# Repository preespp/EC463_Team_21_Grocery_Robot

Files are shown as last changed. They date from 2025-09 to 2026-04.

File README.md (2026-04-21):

# [Team 21 GOFR: Grocery Operations & Fulfillment Robot](https://gofr-2026.github.io/)
<p align="center">
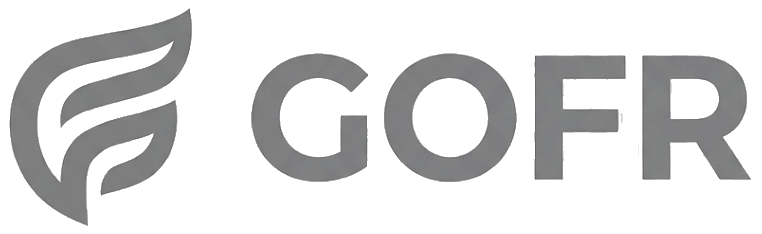
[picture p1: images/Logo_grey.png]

</p>
Our group’s vision is to make everyday shopping more efficient and inclusive. We aim to address issues that would benefit both owners and customers through an intelligent, multi-functional robotic system to improve shelf management and customer experience. Our final delivery would be a multi-wheel robot with functional robotic arm(s), sensors, cameras, and artificial intelligence to assist in employee stocking and customer shopping.

<p align="center">
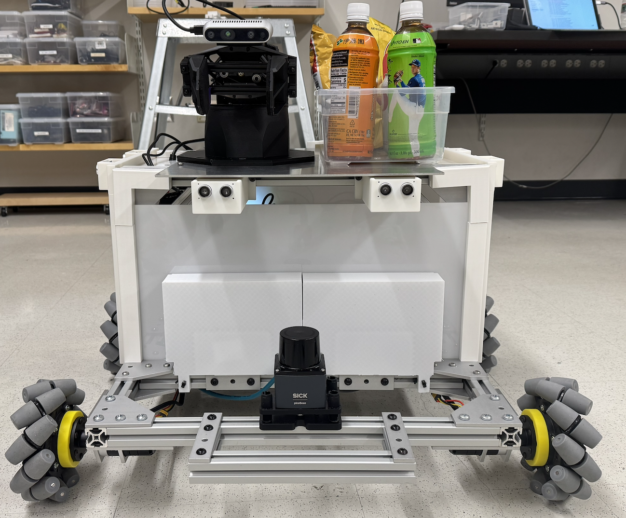
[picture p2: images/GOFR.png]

</p>
<p align="center">
GOFR
</p>

<p align="center">
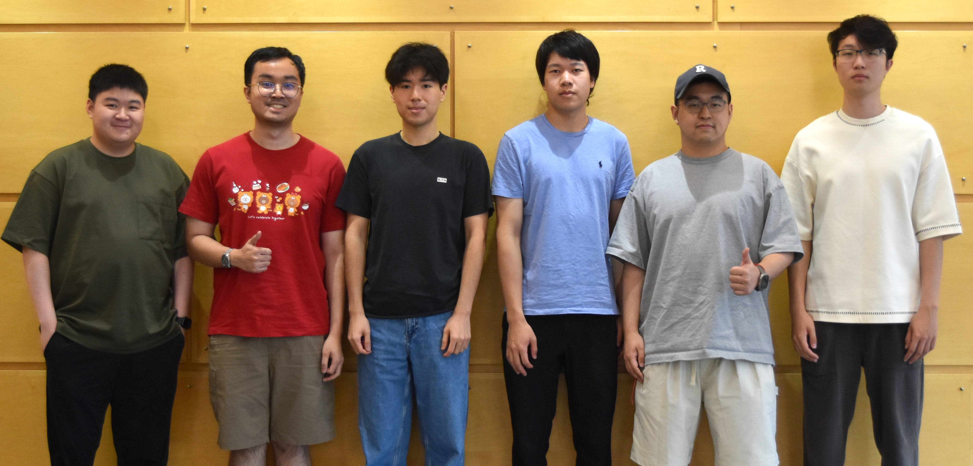
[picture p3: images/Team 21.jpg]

</p>
<p align="center">
Darren Figo Sajino, Pree Simphliphan, Bach Thien Nguyen, Bernie Xu, Xingjian Jiang, Feng Tai
</p>

## Table of Contents
1. [Mission](#mission)
2. [Project Summary](#project-summary)
3. [Problems & Market Analysis](#problems-and-market-analysis)
4. [Goals](#goals)
5. [System Architecture](#system-architecture)
6. [Repository Guide](#repository-guide)
7. [Setup and Instructions](#setup-and-instructions)
8. [Future Development](#future-development)
9. [Team Members](#team-members)
10. [Advisor](#advisor)
11. [Additional Documentations](#additional-documentations)
12. [Additional Links](#team-links)

---
## Mission
To design and develop an intelligent, multi-functional robotic system that streamlines shelf management and enhances customer experience in a grocery store. Our mission is to integrate robotics, sensors, and artificial intelligence to assist employees in stocking tasks, ensure product availability, and provide customers with inclusive, efficient shopping support to make daily activities more convenient.

## Project Summary
In recent years, more and more robots are being employed in order to make daily life more convenient. These systems benefit the users by freeing up time and performing tasks that require precision. The Grocery Robot aims to build a robust robotic system that will perform a wide variety of assistive functions to make grocery shopping more accessible and convenient.

GOFR (Previously, GroceryBot), Grocery Operations & Fulfillment Robot, is an autonomous retail assistant built to support both shopping and restocking workflows. The goal is not to replace store employees, but to reduce repetitive operational burden and improve customer access in environments where reliable staffing and quick item fulfillment matter every day.

At a system level, GOFR combines store-scale mobility with item-level interaction. Customer or staff requests originate in the web app and backend, are resolved against a semantic store map, and are then executed by the ROS 2 autonomy stack. The robot localizes with LiDAR, odometry, and IMU inputs, navigates using Cartographer and Nav2, and uses camera-based perception to verify and align on target items before manipulation. This creates one continuous pipeline from store request to in-aisle execution.

## Problems and Market Analysis
### Market Research
Grocery is one of the largest everyday retail sectors in the world. Based on the team presentation research, the global grocery retail market was valued at roughly $12 trillion in 2023 and is projected to approach $15 trillion by 2030. That scale means even small improvements in stocking efficiency, order fulfillment speed, or shopping accessibility can have meaningful operational impact.

At the same time, grocery stores continue to face persistent labor and workflow pressure. The project research found that 68% of grocery managers report difficulty finding labor for ongoing day-to-day operations. Grocery retail depends on constant movement: checking shelves, restocking items, answering shopper questions, and preparing online or delivery orders. These tasks are repetitive, time-sensitive, and difficult to sustain when staffing is limited. When labor falls short, shelves remain empty longer, order preparation slows down, and employees are forced to divide attention between logistics and customer support.

Accessibility is another major gap in the sector. About 1 in 4 U.S. adults live with a disability, and the presentation research notes that more than 27% of people with disabilities experience a shopping barrier at least occasionally more than once per month. In a grocery setting, that can mean difficulty locating items, reaching products, navigating crowded aisles, or shopping independently without assistance. This makes grocery automation not just an efficiency problem, but also an inclusion problem.

These conditions create a clear opportunity for an assistive retail robot. GOFR is positioned to address both sides of the market need: operational support for stores and improved shopping support for customers. Unlike systems focused only on monitoring inventory, GOFR is intended to connect navigation, perception, and manipulation into one platform that can move through a store, identify a target area, verify products, and participate directly in fulfillment or restocking tasks.

### User Stories and User Requirement
- As a store owner, I want the robot to automatically restock the product to reduce the cost of human labor. 
- As a store owner, I want to have a real-time digital inventory report so I can save time waiting for the report.
- As a store employee, I want the robot to reduce my workload and focus more on more important things or serve the customers.
- As a shop customer, I want the robot to look for the product and navigate to the aisle for me, so that I will not get lost in the store.
- As a customer with special needs, I want to shop independently so that I do not have to ask my friends/relatives for help.
- As a delivery driver, I want to have my customer’s order be ready and packed when I arrive to save time. 

## Goals
### Minimum Viable Product
- Single-Aisle Navigation: fixed route in a mock aisle using line tracing mechanism for navigation with integration of LiDAR and IR Sensors. with 90% success rate under 5 minutes per operation
- Place, Verify & Recovery: Predefined motion of control of robotics arm with range of operation 2-meter height and 2-pound of payload per picking
- Approach & Alignment: Computer Vision to change the orientation of the gripper to pick up product accurately with KPI of 90% success rate
- Safety feature: distance sensor to prevent collision

### Stretch Goals
- Real-time Inventory Report with Database
- Multiple-Aisle Navigation using SLAM algorithms
- Robotics Arm Motions: Integrate Computer Vision or VLA for motion control
- Two modes for customers and store employees
- Online Order Prep from delivery drivers
- Additional Assitance feature on screen for customers
- Safety feature: avoid collision and re-route new navigation

## System Architecture
<p align="center">
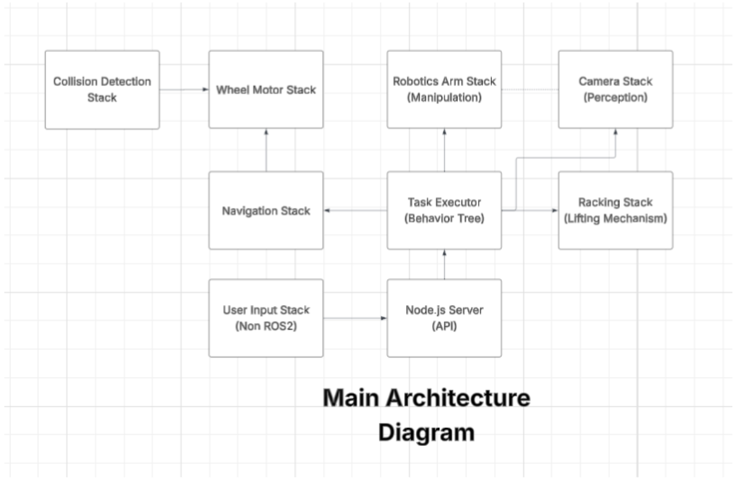
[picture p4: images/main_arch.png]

</p>
<p align="center">
Overall Software System Architecture
</p>

<p align="center">
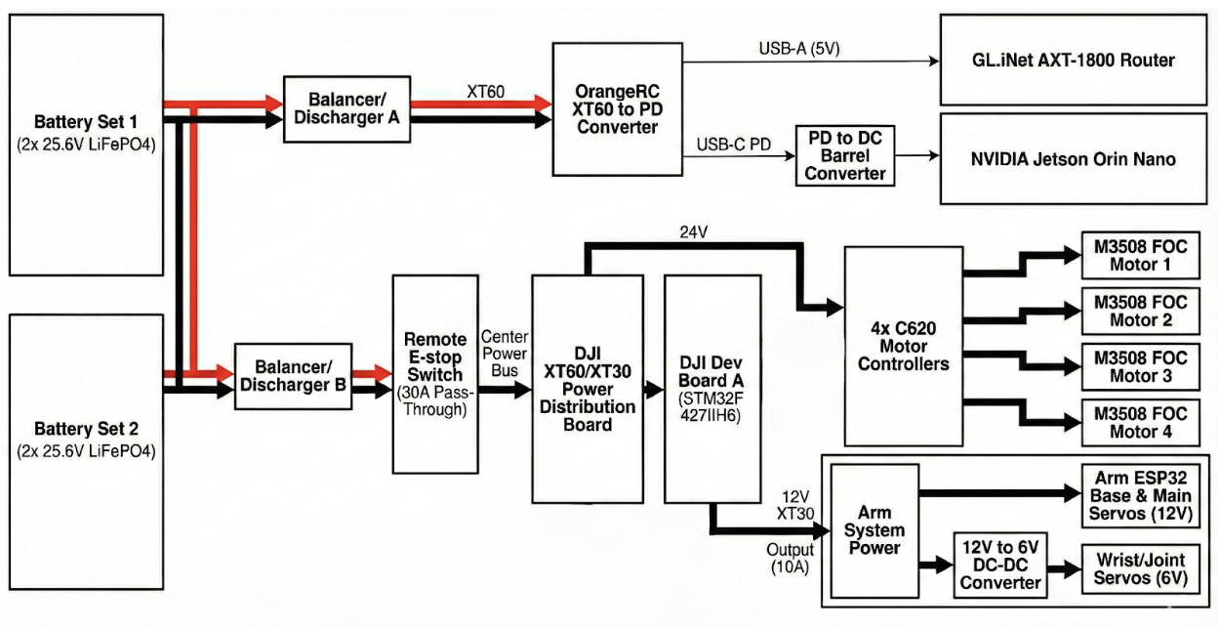
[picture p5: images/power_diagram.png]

</p>
<p align="center">
Power Diagram
</p>

<p align="center">
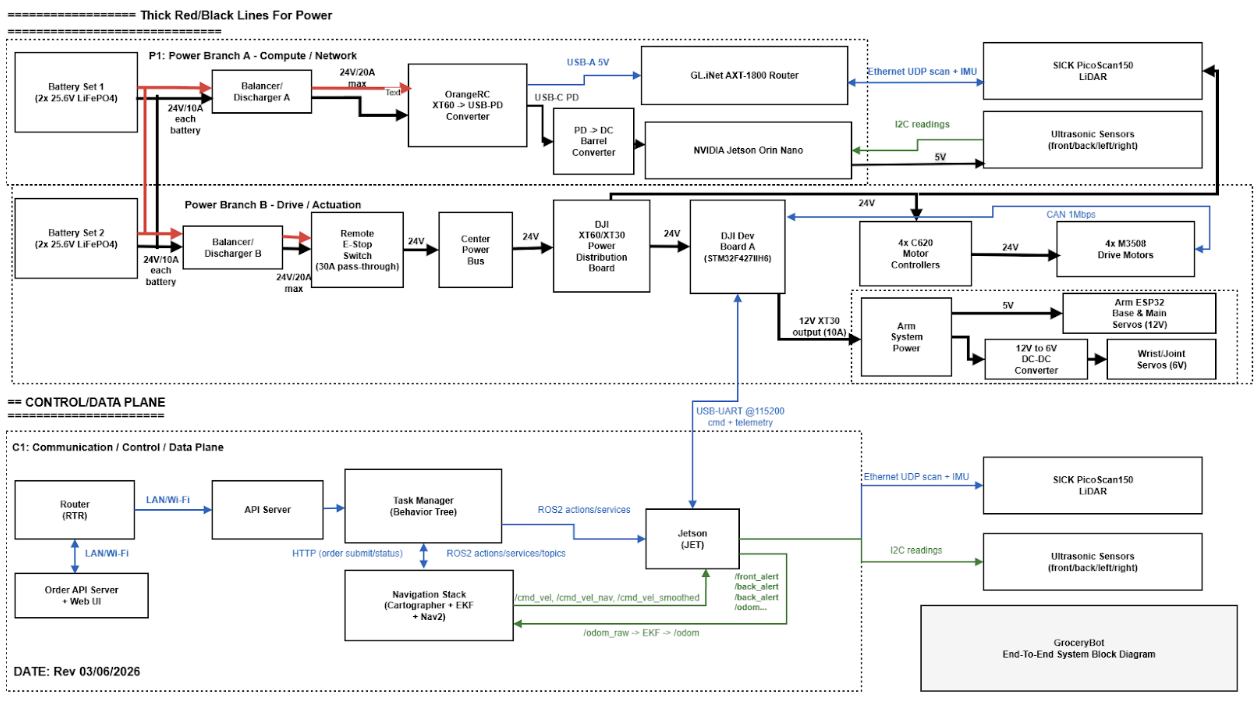
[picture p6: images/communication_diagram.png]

</p>
<p align="center">
Communication Diagram
</p>

<p align="center">
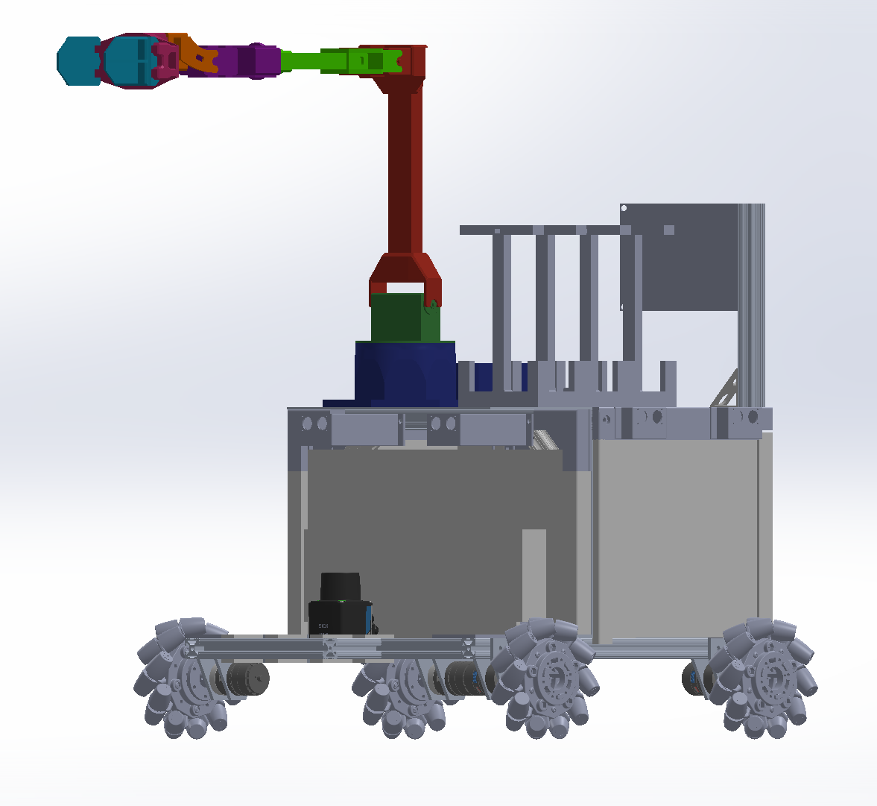
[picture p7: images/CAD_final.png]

</p>
<p align="center">
CAD Mechanical Design
</p>

The current production software path is:

1. Customer or employee requests are created from the app and backend in `order-api-postgre`.
2. The backend stores inventory, user, and semantic-map data in PostgreSQL and exposes APIs used by the web app and the robot.
3. `robot_task_manager` polls or receives orders, resolves semantic targets, and runs the ViperX/customer or restock Behavior Tree.
4. `robot_navigation` localizes the robot with LiDAR, odometry, and IMU, then executes mobile-base navigation through Cartographer and Nav2.
5. `robot_vision` publishes RealSense detections and camera TF data on `/detections_json` and related topics.
6. `robot_manipulation` executes ViperX arm motions through MoveIt and the `/pick_viperx` action server.
7. `robot_perception` publishes ultrasonic collision-alert topics used for safety.
8. The embedded layer is split between `STM32` for the mobile base and `ESP32` projects for ultrasonic sensing, servo experiments, and actuator-side prototyping.

### Software Stack
- Python
- C++
- ROS2 Humble
- Behavior Tree (pytrees)
- OpenCV
- YOLO Model
- IntelRealSense SDK
- Node.js
- Vue.js
- HTML
- CSS
- Javascript
- Gazebo
- Moveit2
- C
- ESP-IDF (Espressif)
- Database (Postgresql)
- Gemini API

### Hardware (Mechanical)
- 12V DC motors -> DJI Motors
- High-torque servo motors
- 3D printing components (PETG)
- Mecanum wheels
- Aluminum framing (80/20 profiles and tubing)
- Acylic Plate
- ViperX 300S Robotic Arm

### Hardware (Electrical & Sensing)
- 2D LiDAR Sensor (SICK picoscan150)
- Odometry Sensor (MCU Gyroscope)
- IntelRealSense Camera
- Ultrasonic Sensors
- 24V LiFePO4 batteries (+ Fuse and Power Distribution)
- ESP32
- STM32
- Remote E-Stop
- NVIDIA Jetson Nano Orin

### Current Status Notes

- The ViperX arm path is the most complete end-to-end manipulation path in the repository today.
- The custom servo-arm and rack path exists in software and mechanical design, but it is still under hardware development and is not yet the main validated runtime path.
- The app, backend, navigation, camera, BT, and ViperX arm flow are already integrated in the repository as the primary demoable full-stack system.

## Repository Guide

The repository is organized around those major subsystems:

- `workspace/src/robot_navigation`: ROS 2 navigation, mapping, localization, Nav2 tuning, semantic map serving, teleoperation, and STM32 serial bridging
- `workspace/src/robot_interfaces`: shared ROS 2 custom messages, services, and actions used across the robot software stack
- `workspace/src/robot_manipulation`: ViperX / VX300 manipulation, MoveIt integration, simulation helpers, BT-facing arm action servers, and rack-related code
- `workspace/src/robot_task_manager`: Behavior Tree orchestration, order intake, blackboard state, semantic target resolution, and task sequencing
- `workspace/src/robot_vision`: RealSense, YOLO-based detection, barcode utilities, and camera TF publishing
- `workspace/src/robot_perception`: ultrasonic collision sensing nodes
- `workspace/src/mvp_robot`: older MVP prototype package kept for reference and legacy experiments
- `order-api-postgre`: Node.js + PostgreSQL backend for orders, inventory, authentication, and semantic-map data
- `order-api-postgre/fleet-manager`: Vue-based operations and fleet dashboard
- `ESP32`: actuator and sensor firmware projects such as ultrasonic I2C, arm servo I2C, and linear-actuator experiments
- `STM32`: mobile-base motor-control firmware and base-control logic
- `Maps`: saved `.pbstream`, `.yaml`, and `.pgm` navigation maps
- `files`: proposal, report PDFs, and exported architecture graphs
- `images`: diagrams, logos, CAD renders, and presentation assets
- `third_party`: vendored dependencies used by the dashboards and robot stack

Sections 5 and 6 have been updated to match the current repository structure and the present validated software flow.

## Setup and Instructions

This section describes the typical software bring-up after the hardware build is complete.

### 1. Finish Hardware Integration First

Before software bring-up, make sure the robot hardware is physically assembled and wired:

- Jetson Nano or robot computer installed and powered
- STM32 base controller connected to motor drivers and serial link
- LiDAR and IMU mounted and wired
- Intel RealSense camera mounted on the ViperX end effector
- ViperX / VX300S arm powered and connected by USB
- ESP32 boards connected for the ultrasonic and actuator subsystems that you plan to use

### 2. Flash Embedded Controllers

#### ESP32

Use the ESP32 folder that matches the hardware subsystem you are flashing:

- `ESP32/ultrasonic_I2C`: ultrasonic-sensor firmware used by the ROS ultrasonic collision stack
- `ESP32/arm_servo_I2C`: custom servo-arm I2C firmware prototype
- `ESP32/linear_actuator`: linear-actuator firmware prototype
- `ESP32/ultrasonic` and `ESP32/servo-component-testing`: Arduino-based bench tests

Typical ESP-IDF flow:

```bash
cd ESP32/ultrasonic_I2C
idf.py set-target esp32
idf.py build
idf.py -p /dev/ttyUSB0 flash monitor
```

Repeat the same pattern for `arm_servo_I2C` or `linear_actuator`, changing the folder and serial port as needed.

For Arduino sketches, flash them from the Arduino IDE with ESP32 board support.

#### STM32

The current mobile-base firmware is in:

```text
STM32/Base_Control_v2/robowalker2024bottominfantry-main/test
```

Open the project from:

```text
STM32/Base_Control_v2/robowalker2024bottominfantry-main/test/test.ioc
```

Then build and flash it with STM32CubeIDE or a compatible STM32 toolchain. This firmware is the base motor-control side used by the ROS navigation serial bridge.

### 3. Install Robot Software On The Jetson / Linux Host

At minimum, install and prepare:

- ROS 2 Humble
- PostgreSQL
- Node.js and npm
- Python 3
- Interbotix dependencies for the ViperX / VX300S arm
- Intel RealSense SDK dependencies

### 4. Build The ROS 2 Workspaces

Build the Interbotix workspace first, then the main robot workspace.

Example:

```bash
cd /Users/preejedi/Desktop/EC463_Team_21_Grocery_Robot/workspace/interbotix_ws
source /opt/ros/humble/setup.bash
colcon build
```

```bash
cd /Users/preejedi/Desktop/EC463_Team_21_Grocery_Robot/workspace
source /opt/ros/humble/setup.bash
source /Users/preejedi/Desktop/EC463_Team_21_Grocery_Robot/workspace/interbotix_ws/install/setup.bash
colcon build --base-paths src
source install/setup.bash
```

### 5. Set Up The App And Backend

Follow the backend setup in `order-api-postgre/README.md`.

Typical order:

1. create the PostgreSQL database and seed it
2. start the Node.js backend
3. start the Vue fleet-manager app

Typical commands:

```bash
cd order-api-postgre
npm install
npm run dev
```

```bash
cd order-api-postgre/fleet-manager
npm install
npm run dev -- --host 0.0.0.0
```

### 6. Run The Robot Software Stack

For the current ViperX-based integrated stack with the app/backend, use separate terminals and source the environment in each one:

```bash
source /opt/ros/humble/setup.bash
source /Users/preejedi/Desktop/EC463_Team_21_Grocery_Robot/workspace/interbotix_ws/install/setup.bash
source /Users/preejedi/Desktop/EC463_Team_21_Grocery_Robot/workspace/install/setup.bash
```

If you want the one-command integrated ROS stack:

```bash
ros2 launch robot_task_manager viperx_nav_camera_bt.launch.py \
  motor_port:=/dev/ttyUSB1 \
  serial_port:=/dev/ttyUSB0 \
  include_ultrasonic:=true
```

This launch is the current combined ROS bring-up for:

- ViperX arm + MoveIt + `/pick_viperx`
- navigation + semantic map
- camera vision
- task-manager BT
- optional ultrasonic sensing

Then run the backend and app in separate terminals:

```bash
cd order-api-postgre
npm run dev
```

```bash
cd order-api-postgre/fleet-manager
npm run dev -- --host 0.0.0.0
```

### 7. Recommended Bring-Up Order For The ViperX + App Demo

1. power the robot and verify STM32 / ESP32 boards are flashed
2. start PostgreSQL, backend, and app
3. source the ROS environments
4. launch `robot_task_manager viperx_nav_camera_bt.launch.py`
5. verify LiDAR, Nav2, camera, and `/pick_viperx` are up
6. log in to the app and create an order or restock task
7. let `robot_task_manager` consume the order and run the BT

### 8. Notes

- The ViperX path is the most complete software path today.
- The custom servo-arm and rack path is still under active hardware development, so its full hardware bring-up is not yet the default deployment workflow.
- If you only want a quick arm-and-camera test, use the package-level instructions in `workspace/src/robot_task_manager/README.md` and `workspace/src/robot_manipulation/README.md`.

## Future Development

- Custom robotic servo arm with racking system: the custom lightweight arm and rack system is still under development and needs components that are light enough for the platform while still handling grocery payloads and arm loads. The related BT logic for the custom rack and servo arm exists in the repository but remains untested on final hardware because that hardware is still under development.
- Integration of camera with the custom servo arm: after the custom arm hardware stabilizes, the next step is to mount and calibrate the camera pipeline for that arm the way the ViperX path already does today.
- Integration of VLA/VLM with the robotic arm: future manipulation work includes using vision-language or vision-language-action systems for higher-level scene understanding, grasp selection, and more adaptive arm behavior.
- Cloud system for the app and our own AI model without relying on Gemini API: the current app uses a Gemini-based integration path, but a future goal is to migrate toward a cloud-hosted system owned by the project, including our own model-serving pipeline.
- Multiple robots working together under one fleet manager: the current software is centered on one robot, but the long-term direction is coordinated multi-robot operation under a single fleet-management interface.

## Team Members
- Bach Thien Nguyen, Mechanical Engineering
- Bernie Xu, Mechanical Engineering
- Darren Figo Sajino, Mechanical Engineering
- Feng Tai, Computer Engineering
- Pree Simphliphan, Computer Engineering
- Xingjian Jiang, Computer Engineering

## Advisor
- Professor Thomas Little

### EC463-464 Instuctors
- Professor Thomas Little
- Professor Ryan Lagoy
- Professor Osama Alshaykh

## Additional Documentations

### Embedded And Backend

- [ESP32 README](./ESP32/README.md)
- [STM32 README](./STM32/README.md)
- [Order API + PostgreSQL README](./order-api-postgre/README.md)

### ROS 2 Packages In `workspace/src`

- [mvp_robot README](./workspace/src/mvp_robot/README.md)
- [robot_interfaces README](./workspace/src/robot_interfaces/README.md)
- [robot_manipulation README](./workspace/src/robot_manipulation/README.md)
- [robot_navigation README](./workspace/src/robot_navigation/README.md)
- [robot_perception README](./workspace/src/robot_perception/README.md)
- [robot_task_manager README](./workspace/src/robot_task_manager/README.md)
- [robot_vision README](./workspace/src/robot_vision/README.md)

### Reports And Project Files In `files`

- [Final Report PDF](./files/BU_GOFR_Grocery_Operations_Fulfillment_Robot.pdf)
- [Project Proposal PDF](./files/Proposal%20for%20EC463.pdf)

## Additional Links

## Team links
- [Team Google Drive](https://drive.google.com/drive/folders/1yiAgVb-4LaUo8HKmD3yormvIIuaboWg9)

## Course links
- [ECE Senior Design Piazza Site](https://piazza.com/bu/fall2025/ec463/home)
- [Blackboard](http://learn.bu.edu/)

## Optional features links
- [Team Jira](https://seniordesign-team-21.atlassian.net/jira/software/projects/SCRUM/summary)
- [Project Website](https://gofr-2026.github.io/)
- [YouTube Demo Video](https://www.youtube.com/watch?v=yoCo3-0eruo&t=9s)

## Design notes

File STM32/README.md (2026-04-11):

# STM32 Firmware

This folder contains the STM32 firmware used for the mobile base motor-control side of GOFR.

## What It Contains

- `Base_Control_v2/robowalker2024bottominfantry-main/`: the current STM32 base-control project
- `docs/CONTROL_LOGIC.md`: control-logic notes for the mecanum chassis and motor pipeline
- `test/test.ioc`: STM32CubeMX / STM32CubeIDE project configuration for the checked-in build
- `tools/pc_control.py`: serial testing helper for host-side validation

## Current Role In The Robot

The STM32 side is used for:

- mecanum wheel motor control
- receiving velocity commands from the ROS navigation bridge
- returning odometry / telemetry used by the higher-level ROS 2 stack

## Typical Workflow

1. Open the STM32 project from:

```text
STM32/Base_Control_v2/robowalker2024bottominfantry-main/test/test.ioc
```

2. Build and flash it with STM32CubeIDE or a compatible STM32 toolchain.

3. Connect the controller to the robot computer so `robot_navigation/nav2_serial_bridge` can communicate with it over serial.

## Related Documentation

- [CONTROL_LOGIC.md](/Users/preejedi/Desktop/EC463_Team_21_Grocery_Robot/STM32/Base_Control_v2/robowalker2024bottominfantry-main/docs/CONTROL_LOGIC.md)

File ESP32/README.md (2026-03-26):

# ESP32 Projects

This folder contains various ESP32-based projects and components for the Grocery Robot system.

## Folder Structure

- **arm_servo_I2C/**: ESP32 project for controlling arm servos via I2C interface. Includes Python script and ESP-IDF build files.
- **linear_actuator/**: ESP32 project for linear actuator control using ESP-IDF.
- **servo-component-testing/**: Arduino sketches for testing servo components, including lift tests and repeatability tests.
- **ultrasonic/**: Arduino sketch for ultrasonic sensor functionality.
- **ultrasonic_I2C/**: ESP32 project for ultrasonic sensors with I2C communication using ESP-IDF.

## Getting Started

Each subfolder contains its own build configuration and source code. Refer to the individual README files or project files for setup instructions.

For ESP-IDF projects, ensure you have the ESP-IDF environment set up. For Arduino projects, use the Arduino IDE with ESP32 board support.

## Dependencies

- ESP-IDF (for ESP-IDF projects)
- Arduino IDE with ESP32 core (for .ino files)
- Required hardware: ESP32 microcontroller, servos, ultrasonic sensors, etc.

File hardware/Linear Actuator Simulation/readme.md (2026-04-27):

This folder contains files used to perform linear actuator reaction force and torque simulations, as well as a full assembly of the linear actuator and racking system that we implemented.

The following repository was used as a starting point for this simulation:
https://github.com/PhamDuyAnh/Design_Linear_Actuator/tree/master/Motion%20Study%20-%20linear%20actuator

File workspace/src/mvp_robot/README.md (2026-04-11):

# mvp_robot

`mvp_robot` is the legacy minimum-viable-product package from the early project phase. It was used to prototype the first end-to-end robot behaviors before the codebase was split into the newer dedicated packages such as `robot_navigation`, `robot_vision`, `robot_perception`, `robot_manipulation`, and `robot_task_manager`.

## What This Package Is

This package collects older prototype nodes for:

- central orchestration
- mock UI input
- wheel and navigation experiments
- camera and distance-sensor experiments
- arm control experiments
- Gazebo bridge testing

Use this package mainly for historical reference, early demos, or small isolated tests. For the current production stack, prefer the newer dedicated packages in `workspace/src`.

## Tech Stack

- ROS 2 Humble
- Python ROS 2 nodes (`rclpy`)
- custom interfaces from `robot_interfaces`
- OpenCV / CV bridge for camera work
- simple launch files for mock integration tests

## Main Nodes

- `central`: early orchestration and mock product lookup
- `ui_input`: prototype UI input node
- `navigation`: prototype movement/navigation logic
- `wheel_motor`: wheel motor experiment node
- `distance_sensor`: legacy distance sensor node
- `camera_vision`: prototype camera node
- `arm_controller`: prototype arm controller
- `arm_to_gazebo`: bridge from ROS commands to Gazebo testing

## Launch Files

- `launch/mvp_mock.py`: starts `central`, `distance_sensor`, and `camera_vision`
- `launch/product_query_mock.py`: starts `central` and `ui_input`

## Build

```bash
cd /Users/preejedi/Desktop/EC463_Team_21_Grocery_Robot/workspace
source /opt/ros/humble/setup.bash
colcon build --packages-select mvp_robot robot_interfaces
source install/setup.bash
```

## How To Run

Run the small mock stack:

```bash
ros2 launch mvp_robot mvp_mock.py
```

Run the product-query mock flow:

```bash
ros2 launch mvp_robot product_query_mock.py
```

Run individual nodes:

```bash
ros2 run mvp_robot central
ros2 run mvp_robot ui_input
ros2 run mvp_robot navigation
ros2 run mvp_robot wheel_motor
ros2 run mvp_robot camera_vision
ros2 run mvp_robot distance_sensor
ros2 run mvp_robot arm_controller
ros2 run mvp_robot arm_to_gazebo
```

## Notes

- This package is older than the current split architecture, so some flows are prototype-only.
- If you are working on the current grocery robot stack, start with the package-specific READMEs in the newer packages instead of adding new work here.

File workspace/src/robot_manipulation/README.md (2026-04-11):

# robot_manipulation

`robot_manipulation` is the robot arm and rack package. It contains the ViperX / VX300 manipulation stack, MoveIt integration, BT-facing arm action servers, simulation helpers, rack control, and supporting launch/config files.

## What This Package Is

This package is responsible for:

- bringing up the Interbotix VX300 or VX300S arm
- exposing the BT-facing `/pick_viperx` action server
- running MoveIt-based manipulation
- running optional camera-driven auto-pick flows
- hosting older standalone arm waypoint and Gazebo test workflows
- controlling rack-related subsystems

## Tech Stack

- ROS 2 Humble
- C++ nodes with `rclcpp` and `rclcpp_action`
- MoveIt 2
- Interbotix XS arm stack
- TF2
- optional Gazebo / `ros_gz`
- shared `robot_interfaces` actions

## Main Executables And Roles

- `viperx_arm_server`: main BT-facing arm action server on `/pick_viperx`
- `vision_auto_pick.py`: listens to vision detections and sends pick goals
- `arm_waypoint_server`: older standalone waypoint-based action server
- `arm_controller`, `arm_demo_controller`, `arm_to_gazebo`, `rack_controller`: older or specialized test/control nodes

## Key Launch Files

- `vx300_bringup.launch.py`: bring up real VX300 / VX300S hardware
- `vx300_moveit.launch.py`: MoveIt + controllers + optional `/pick_viperx`
- `vx300_auto_pick.launch.py`: MoveIt plus auto-pick flow, optionally with `camera_vision`
- `vx300_auto_pick_measured_tf.launch.py`: measured eye-in-hand TF version of auto-pick
- `viperx_arm_server.launch.py`: launch only the BT-facing arm action server stack
- `arm_waypoint_launch.py`: older standalone waypoint server flow
- `arm_sim_launch.py`: older Gazebo arm simulation flow
- `assembly_arm_sim_launch.py`: CAD assembly arm simulation flow
- `rack_launch.py`: rack subsystem

## Important Config And Asset Files

- `config/viperx_arm_server.yaml`: preset commands, place pose, return pose, gripper behavior
- `config/vx300_auto_pick.yaml` and `config/vx300s_auto_pick.yaml`: auto-pick behavior
- `config/vx300s_moveit_modes.yaml`: model-specific hardware mode settings
- `meshes/`: CAD and robot meshes referenced by URDF / Xacro
- `urdf/`: arm and simulation descriptions

## Build

```bash
cd /Users/preejedi/Desktop/EC463_Team_21_Grocery_Robot/workspace
source /opt/ros/humble/setup.bash
source /Users/preejedi/Desktop/EC463_Team_21_Grocery_Robot/workspace/interbotix_ws/install/setup.bash
colcon build --base-paths src --packages-select robot_interfaces robot_manipulation robot_vision
source install/setup.bash
```

## Environment

Use this environment in terminals that run the ViperX stack:

```bash
source /opt/ros/humble/setup.bash
source /Users/preejedi/Desktop/EC463_Team_21_Grocery_Robot/workspace/interbotix_ws/install/setup.bash
source /Users/preejedi/Desktop/EC463_Team_21_Grocery_Robot/workspace/install/setup.bash
```

## Common Workflows

### 1. Bring Up MoveIt And `/pick_viperx`

```bash
ros2 launch robot_manipulation vx300_moveit.launch.py \
  robot_model:=vx300s robot_name:=vx300s motor_port:=/dev/ttyUSB1
```

This is the main launch for BT-driven arm control.

### 2. Run Auto-Pick With The Current Default Camera Calibration

```bash
ros2 launch robot_manipulation vx300_auto_pick.launch.py \
  robot_model:=vx300s robot_name:=vx300s motor_port:=/dev/ttyUSB1 \
  launch_camera_vision:=true
```

### 3. Run Auto-Pick With Measured Camera TF

```bash
ros2 launch robot_manipulation vx300_auto_pick_measured_tf.launch.py \
  robot_model:=vx300s robot_name:=vx300s motor_port:=/dev/ttyUSB1
```

### 4. Preview-Only Validation Without Hardware Motion

```bash
ros2 launch robot_manipulation vx300_auto_pick_measured_tf.launch.py \
  robot_model:=vx300s robot_name:=vx300s motor_port:=/dev/ttyUSB1 \
  use_viperx_preview:=true
```

### 5. Run The Older Standalone Waypoint Server

```bash
ros2 launch robot_manipulation arm_waypoint_launch.py
```

Send a test goal:

```bash
ros2 action send_goal /pick_arm_waypoint robot_interfaces/action/PickArm \
"{target_pose: {header: {frame_id: 'base_link'}, pose: {position: {x: 0.0, y: 0.0, z: 0.0}, orientation: {x: 0.0, y: 0.0, z: 0.0, w: 1.0}}}, planning_group: 'home', ee_link: '', pregrasp_offset_m: 0.0, retreat_offset_m: 0.0, gripper_close_position: -1.0, use_cartesian_approach: false}" \
--feedback
```

### 6. Run The CAD Assembly Arm Simulation

Build example:

```bash
cd ~/Desktop/EC463_Team_21_Grocery_Robot/workspace
source /opt/ros/humble/setup.bash
colcon build --packages-select robot_manipulation --cmake-force-configure --cmake-args \
  -DBUILD_ROBOT_MANIPULATION_NODES=ON \
  -DBUILD_ARM_MOTOR_NODE=OFF \
  -DBUILD_ARM_CONTROLLER_NODE=OFF \
  -DBUILD_ARM_DEMO_CONTROLLER_NODE=ON \
  -DBUILD_ARM_TO_GAZEBO_NODE=ON \
  -DBUILD_ARM_WAYPOINT_SERVER_NODE=OFF \
  -DBUILD_RACK_CONTROLLER_NODE=OFF
source install/setup.bash
```

Then:

```bash
ros2 launch robot_manipulation assembly_arm_sim_launch.py run_arm_controller:=false run_demo_controller:=true
```

## Camera Auto-Pick Notes

- `camera_vision` publishes `/detections_json`
- `vision_auto_pick.py` transforms detections into the arm base frame
- `/pick_viperx` accepts `robot_interfaces/action/PickArm` goals
- model-specific auto-pick configs are preferred when present, such as `vx300s_auto_pick.yaml`

## Simulation And Mesh Notes

- `meshes/` contains the CAD mesh files used by the URDF and Gazebo flows
- the CAD assembly arm expects filenames such as `base_link.stl`, `inner-ring_1.stl`, `outer-ring_1.stl`, and the other checked-in mesh assets

## Git Notes

The Interbotix folders in `workspace/interbotix_ws/src/` are local upstream dependencies and separate repositories. When committing manipulation changes in the main project repo, stage `workspace/src/robot_manipulation` and avoid accidentally staging the nested Interbotix repos.

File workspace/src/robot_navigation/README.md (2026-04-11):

# robot_navigation

`robot_navigation` is the mobile-base navigation package for the grocery robot. It provides LiDAR bringup, Cartographer mapping/localization, Nav2 integration, STM32 serial bridging, teleoperation, map save/export helpers, semantic map serving, and CLI shortcuts through `nav_assistant`.

## What This Package Is

This package is responsible for:

- LiDAR and IMU launch integration
- Cartographer mapping and localization
- Nav2 localization and planning stack
- serial bridge from ROS `/cmd_vel` topics to the base controller
- raw odometry and optional EKF fusion
- semantic map service support for higher-level task planning
- teleop, goal sending, waypoint sending, and motion macros

## Tech Stack

- ROS 2 Humble
- Python ROS 2 nodes with `rclpy`
- Cartographer
- Nav2
- `robot_localization`
- TF2
- serial bridge tooling for the base controller
- shared interfaces from `robot_interfaces`

## Main Components

- `robot_navigation/nav_assistant.py`: one-command CLI helper
- `robot_navigation/nav2_serial_bridge.py`: `/cmd_vel` to STM32 bridge and `/odom_raw` publisher
- `launch/slam_mapping_stack.launch.py`: mapping stack
- `launch/nav2_localization_stack.launch.py`: localization + Nav2 + semantic map stack
- `launch/cartographer_mapping.launch.py` and `launch/cartographer_localization.launch.py`: Cartographer-only pieces

## Build

```bash
cd /Users/preejedi/Desktop/EC463_Team_21_Grocery_Robot/workspace
source /opt/ros/humble/setup.bash
colcon build --symlink-install --packages-select robot_navigation
source install/setup.bash
```

## Main Command Entry Point

```bash
ros2 run robot_navigation nav_assistant <subcommand>
```

## Common Workflows

### 1. Run Mapping

```bash
ros2 run robot_navigation nav_assistant mapping-stack
```

Use the higher-quality profile if needed:

```bash
ros2 run robot_navigation nav_assistant mapping-stack \
  --cartographer-config-basename pico_2d_mapping_quality.lua
```

Optional extras:

```bash
ros2 run robot_navigation nav_assistant mapping-stack --with-rviz true --with-collision true
```

### 2. Teleoperate The Robot

```bash
ros2 run robot_navigation nav_assistant teleop
ros2 run robot_navigation nav_assistant teleop-collision
```

### 3. Save And Export A Map

```bash
ros2 run robot_navigation nav_assistant save-map --map-name testmapMain
ros2 run robot_navigation nav_assistant export-map --map-name testmapMain
```

### 4. Run Localization + Nav2

```bash
ros2 run robot_navigation nav_assistant localization-stack --map-name testmapMain --with-nav2-rviz true
```

For headless systems:

```bash
ros2 run robot_navigation nav_assistant localization-stack --map-name testmapMain --with-nav2-rviz false
```

### 5. Send Goals Or Waypoints

```bash
ros2 run robot_navigation nav_assistant goal --x 1.0 --y 0.0 --yaw 0.0
```

```bash
ros2 run robot_navigation nav_assistant waypoints \
  --pose 1.0,0.0,0.0 \
  --pose 1.5,0.5,0.0 \
  --pose 0.5,1.0,0.0
```

### 6. Run Motion Macros

```bash
ros2 run robot_navigation nav_assistant motion --preset box_loop --topic /cmd_vel
ros2 run robot_navigation nav_assistant motion-pad --topic /cmd_vel
```

### 7. Direct Launch Usage

```bash
ros2 launch robot_navigation slam_mapping_stack.launch.py
```

```bash
ros2 launch robot_navigation nav2_localization_stack.launch.py \
  pbstream_file:=/Users/preejedi/Desktop/EC463_Team_21_Grocery_Robot/Maps/testmapMain.pbstream \
  map_yaml:=/Users/preejedi/Desktop/EC463_Team_21_Grocery_Robot/Maps/testmapMain.yaml \
  nav2_params_file:=/Users/preejedi/Desktop/EC463_Team_21_Grocery_Robot/workspace/src/robot_navigation/config/nav2_params_smac_mppi_omni.yaml \
  with_nav2_rviz:=true
```

## Current Defaults

- LiDAR frame: `lidar_link`
- IMU frame: `imu_link`
- raw bridge odom: `/odom_raw`
- EKF output: `/odom`
- localization command topics bridged by default: `["/cmd_vel"]`
- current Nav2 params file: `config/nav2_params_smac_mppi_omni.yaml`
- current global planner: `nav2_smac_planner/SmacPlanner2D`
- current local controller: `nav2_mppi_controller::MPPIController`

## Collision Detection Integration

If ultrasonic collision detection is connected, run:

```bash
ros2 launch robot_perception ultrasonic_launch.py
```

If the hardware is not connected and you need to fake safe topics during testing:

```bash
ros2 topic pub -r 100 /front_alert std_msgs/msg/Bool "{data: false}"
ros2 topic pub -r 100 /left_alert std_msgs/msg/Bool "{data: false}"
ros2 topic pub -r 100 /right_alert std_msgs/msg/Bool "{data: false}"
ros2 topic pub -r 100 /back_alert std_msgs/msg/Bool "{data: false}"
```

## Map Output

By default, maps are saved to the repo-level `Maps/` folder as:

- `<map_name>.pbstream`
- `<map_name>.yaml`
- `<map_name>.pgm`

## Helpful Checks

```bash
ros2 run robot_navigation nav_assistant print-runbook --map-name testmapMain
ros2 run robot_navigation nav_assistant quick-check
```

## Notes

- Disable EKF only for troubleshooting.
- Mapping enables the base-link crop filter by default; localization keeps it off unless explicitly enabled.
- This package is the navigation side of the current production stack, not the old MVP prototype flow.

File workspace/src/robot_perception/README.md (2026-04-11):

# robot_perception

`robot_perception` contains the ROS 2 ultrasonic collision-sensing stack for the grocery robot. It reads distance data from ESP32-based I2C sensor boards and publishes side-specific alert topics for use by navigation and safety logic.

## What This Package Is

This package is responsible for:

- reading ultrasonic distance data from ESP32 boards over I2C
- converting those readings into Boolean collision alerts
- launching the four directional ultrasonic readers used on the robot

## Tech Stack

- ROS 2 Humble
- Python ROS 2 nodes with `rclpy`
- `smbus2` / Linux I2C access
- ESP32 firmware integration over I2C

## Main Node

- `distance_sensor`: reads one ESP32 board and publishes a side-specific alert topic such as `/front_alert`

## Current Hardware Layout

Each ESP32 board covers one side of the robot:

- `F` = front
- `B` = back
- `L` = left
- `R` = right

Each ESP32 reads two ultrasonic sensors and returns two little-endian `float` values over I2C.

## Wiring Expectations

Ultrasonic sensor channels on each ESP32:

- channel 1: `TRIG -> GPIO4`, `ECHO -> GPIO16`
- channel 2: `TRIG -> GPIO17`, `ECHO -> GPIO34`

I2C pins on each ESP32:

- `SDA -> GPIO21`
- `SCL -> GPIO22`

Power:

- ultrasonic `VCC -> 5V`
- ultrasonic `GND -> GND`
- ESP32 ground must be shared with the robot computer / I2C master ground

## Important Electrical Note

Typical ultrasonic `ECHO` lines are `5V`, while ESP32 GPIO is `3.3V` only. Use a voltage divider or level shifter on each `ECHO` line before it reaches the ESP32.

## Current Launch Mapping

`launch/ultrasonic_launch.py` starts four `distance_sensor` nodes:

- `front` at `0x09`
- `left` at `0x10`
- `right` at `0x11`
- `back` at `0x12`

Current shared defaults:

- bus: `7`
- rate: `100.0`
- threshold: `0.20 m`

## Build

```bash
cd /Users/preejedi/Desktop/EC463_Team_21_Grocery_Robot/workspace
source /opt/ros/humble/setup.bash
colcon build --packages-select robot_perception
source install/setup.bash
```

## How To Run

Run the full ultrasonic stack:

```bash
ros2 launch robot_perception ultrasonic_launch.py
```

Run one node manually:

```bash
ros2 run robot_perception distance_sensor --ros-args \
  -p bus:=7 \
  -p addr:=9 \
  -p rate:=100.0 \
  -p threshold_m:=0.20 \
  -p name:=front
```

## Published Topics

The launch file creates these alert topics:

- `/front_alert`
- `/left_alert`
- `/right_alert`
- `/back_alert`

## Quick Checks

```bash
ls /dev/i2c-7
i2cdetect -y 7
ros2 topic list | grep alert
ros2 topic echo /front_alert
```

## Troubleshooting

- If `/dev/i2c-7` is missing, confirm the Linux I2C bus is enabled and the bus number is correct.
- If a board does not show up in `i2cdetect`, check power, address, wiring, and shared ground.
- If the node logs I2C read failures, confirm the address in the launch file matches the firmware flashed onto the ESP32.
- If alerts never trigger, verify the threshold and make sure the ESP32 is returning valid distances.

## Related Firmware

The matching ESP32 firmware lives in:

- `ESP32/ultrasonic_I2C/main/ultrasonic_i2c.c`

If pin assignments or packet layout change in firmware, update this README and the ROS side together.

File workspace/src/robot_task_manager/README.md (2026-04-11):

# robot_task_manager

`robot_task_manager` is the Behavior Tree orchestration package for the grocery robot. It accepts orders, manages shared blackboard state, resolves semantic targets, coordinates navigation and manipulation, and runs the customer and restock workflows for the ViperX-based system.

## What This Package Is

This package is responsible for:

- running the Behavior Tree executor
- managing order intake from ROS services and the Node.js backend
- maintaining blackboard state for navigation, semantics, and manipulation
- coordinating navigation goals, shelf targets, camera verification, and arm actions
- running customer and employee / restock workflows

## Tech Stack

- ROS 2 Humble
- Python ROS 2 nodes with `rclpy`
- `py_trees` Behavior Trees
- TF2
- shared custom interfaces from `robot_interfaces`
- integration with `robot_navigation`, `robot_manipulation`, and `robot_vision`

## Main Nodes

- `bt_executor`: older BT entrypoint
- `bt_executor_viperX`: current ViperX-focused Behavior Tree executor

## Main Files And Modules

- `robot_task_manager/bt_executor_viperx.py`: main runtime executor
- `robot_task_manager/blackboard.py`: shared state setup and reset helpers
- `robot_task_manager/trees/customer_viperx.py`: ViperX customer workflow
- `robot_task_manager/trees/restock_viperx.py`: ViperX employee / restock workflow
- `robot_task_manager/bt_nodes/`: BT nodes for navigation, semantics, arm actions, rack actions, and ViperX vision handling
- `config/viperx_bt_states.yaml`: BT-side command naming template

## High-Level ViperX Flow

For the customer workflow, the package currently does the following:

1. accepts or polls an order
2. resolves the semantic target into a navigation goal and shelf metadata
3. navigates to the target area unless navigation is skipped
4. moves the ViperX arm to an observation pose
5. verifies the object from `/detections_json`
6. transforms the detected point into `vx300/base_link`
7. sends a motion request to `/pick_viperx`
8. places the item in a basket pose

## Build

```bash
cd /Users/preejedi/Desktop/EC463_Team_21_Grocery_Robot/workspace
source /opt/ros/humble/setup.bash
source /Users/preejedi/Desktop/EC463_Team_21_Grocery_Robot/workspace/interbotix_ws/install/setup.bash
colcon build --base-paths src --packages-select robot_interfaces robot_manipulation robot_task_manager robot_vision
source install/setup.bash
```

## Environment

```bash
source /opt/ros/humble/setup.bash
source /Users/preejedi/Desktop/EC463_Team_21_Grocery_Robot/workspace/interbotix_ws/install/setup.bash
source /Users/preejedi/Desktop/EC463_Team_21_Grocery_Robot/workspace/install/setup.bash
```

## Common Workflows

### 1. Recommended Full Integrated Launch

Use the package launch file that starts arm, navigation, camera, BT, and optional ultrasonic sensing:

```bash
ros2 launch robot_task_manager viperx_nav_camera_bt.launch.py \
  motor_port:=/dev/ttyUSB1 \
  serial_port:=/dev/ttyUSB0 \
  include_ultrasonic:=true
```

Useful arguments:

- `include_ultrasonic:=true|false`
- `launch_navigation:=true|false`
- `skip_navigation:=true|false`
- `show_live_window:=true|false`
- `pbstream_file:=...`
- `map_yaml:=...`

### 2. Quick Test: Arm + Camera + BT Only

Terminal 1:

```bash
ros2 launch robot_manipulation vx300_moveit.launch.py \
  robot_model:=vx300s robot_name:=vx300s motor_port:=/dev/ttyUSB1
```

Terminal 2:

```bash
ros2 run robot_vision camera_vision --ros-args \
  -p parent_frame:=vx300s/ee_gripper_link \
  -p camera_mount_frame:=camera_mount_frame \
  -p camera_optical_frame:=camera_color_optical_frame
```

Terminal 3:

```bash
ros2 run robot_task_manager bt_executor_viperX --ros-args -p skip_navigation:=true
```

Terminal 4:

```bash
ros2 service call /order/new robot_interfaces/srv/NewOrder "{order: {order_id: 1, role: customer, requester_id: test, items: [{product_id: TEST1, name: bottle, aisle: '0', rack: 0, shelf_level: 1, qty: 1, price: 0.0, stock: 1}]}}"
```

### 3. Full Stack With Backend / UI

Run arm, camera, and BT as above, but start the BT without `skip_navigation:=true` and launch the normal Node.js backend / UI separately.

## Order Intake

The executor provides:

- `/order/new` using `robot_interfaces/srv/NewOrder`

It can also poll the Node.js backend at `http://localhost:3000` for orders.

## Vision And Semantic Integration

- camera detections come from `robot_vision/camera_vision.py` on `/detections_json`
- semantic resolution comes from `/semantic_map/resolve_target`
- arm motions are sent through `robot_interfaces/action/PickArm` to `/pick_viperx`

The BT uses command-style arm presets such as:

- `startup_arm_pose`
- `return_arm_pose`
- `place_arm_pose`
- `shelf_level_1_pose`
- `shelf_level_2_pose`
- `shelf_level_3_pose`

Those command names must also exist in `robot_manipulation/config/viperx_arm_server.yaml`.

## Blackboard Formats

Important blackboard shapes include:

- `bb.nav_goal = (x, y, yaw)`
- `bb.shelf_pose = {"command": "shelf_level_2_pose"}`
- `bb.detected_object_pose = {"frame_id": "vx300/base_link", "x": ..., "y": ..., "z": ...}`

## Notes

- `skip_navigation:=true` is useful for table demos and arm-only debugging.
- The ViperX workflow assumes command-based shelf poses rather than direct z-height control.
- If a new BT command is added, the arm server config must be updated to recognize it.

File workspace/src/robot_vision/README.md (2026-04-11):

# robot_vision

`robot_vision` contains the camera and detection stack for the grocery robot. It provides RealSense-based object perception, barcode utilities, and published detection data used by the manipulation and task-management packages.

## What This Package Is

This package is responsible for:

- running the main `camera_vision` node used by the ViperX stack
- publishing object detections on `/detections_json`
- publishing camera-related TF frames used by the arm and BT flows
- hosting an additional `realsense_combination` node for alternate payload/image publishing
- providing barcode-related utilities

## Tech Stack

- ROS 2 Humble
- Python ROS 2 nodes with `rclpy`
- Intel RealSense via `pyrealsense2`
- OpenCV and `cv_bridge`
- YOLO / Ultralytics object detection
- TF2 broadcasting

## Main Executables

- `camera_vision`: main production camera + detection node
- `realsense_combination`: alternate RealSense pipeline node
- `bar_code`: barcode utility node

## Main Launch Files

- `launch/realsense_combination.launch.py`: launch wrapper for the `realsense_combination` node

## Build

```bash
cd /Users/preejedi/Desktop/EC463_Team_21_Grocery_Robot/workspace
source /opt/ros/humble/setup.bash
colcon build --packages-select robot_vision
source install/setup.bash
```

## How To Run

### 1. Run The Main Camera Node

```bash
ros2 run robot_vision camera_vision --ros-args \
  -p parent_frame:=vx300s/ee_gripper_link \
  -p camera_mount_frame:=camera_mount_frame \
  -p camera_optical_frame:=camera_color_optical_frame
```

Enable the live preview window:

```bash
ros2 run robot_vision camera_vision --ros-args \
  -p show_live_window:=true \
  -p parent_frame:=vx300s/ee_gripper_link \
  -p camera_mount_frame:=camera_mount_frame \
  -p camera_optical_frame:=camera_color_optical_frame
```

### 2. Run The Alternate RealSense Combination Node

```bash
ros2 launch robot_vision realsense_combination.launch.py
```

Or directly:

```bash
ros2 run robot_vision realsense_combination
```

### 3. Run The Barcode Utility

```bash
ros2 run robot_vision bar_code
```

## Main Published Data

`camera_vision` publishes a JSON string on `/detections_json`.

Each detection includes fields such as:

- `class_id`
- `class_name`
- `confidence`
- `bbox`
- `center_px`
- `distance_m`
- `surface_distance_m`
- `point_camera_optical_m`
- `grasp_px`

The payload also includes frame metadata such as:

- `camera_optical_frame`
- `camera_mount_frame`
- `timestamp`

## Integration Notes

- `robot_task_manager` consumes `/detections_json` during the ViperX BT flow.
- `robot_manipulation` can use the detections for auto-pick and frame transformation into the arm base.
- The main ViperX camera parent frame is usually `vx300s/ee_gripper_link`.

## Notes

- The package expects the RealSense and vision dependencies to be installed on the machine.
- `camera_vision` is the node used by the current production ViperX stack.

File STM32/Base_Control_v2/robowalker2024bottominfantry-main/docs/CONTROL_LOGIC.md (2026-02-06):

# RoboWalker Bottom Infantry Control Logic Notes

This document summarizes the control logic, chassis kinematics, and PID usage for the STM32 project in this repo. It also lists executable vs separable code, required hardware, and the key callable APIs.

## Current implementation snapshot (chassis-only, PC UART2)
- Input: PC UART2 frame (0xAC header, 5 floats + key mask + switches, checksum) at 115200 baud (8-N-1).
- Scheduling: 1 ms PC parse + chassis target update, 2 ms chassis resolution/control, 1 ms CAN send + 5 ms Serialplot telemetry.
- Chassis: 4 mecanum, C620 current mode, outer PID on vx/vy/omega, wheel odom only (no IMU). Wheel direction mismatches (FR/RR wiring) are handled via a compile-time `Wheel_Direction` sign map when sampling encoder data and when issuing motor currents.

## Project layout and entry points
- Core entry point: `test/Core/Src/main.c` calls `Task_Init()` and `Task_Loop()`.
- Scheduler and callbacks: `test/User_File/5_Task/tsk_config_and_callback.cpp` wires CAN/UART interrupts to device callbacks and runs periodic control loops on TIM5.
- High level control: `test/User_File/4_Interaction/ita_robot.cpp` contains the mode logic and per subsystem control.
- Chassis kinematics and dynamics: `test/User_File/3_Chariot/1_Module/Chassis/crt_chassis.cpp`.
- PID algorithm: `test/User_File/1_Middleware/2_Algorithm/PID/alg_pid.cpp`.

## Executable control flow (what actually runs)
### Main loop
- `Task_Init()` initializes BSP power, CAN, UART, timers, watchdog, Serialplot, and all robot modules, then starts timers.
- `Task_Loop()` runs in the main while loop ~~and updates the referee UI~~ (currently empty stub).

### TIM5 1 ms scheduler
Executed in `Task1ms_TIM5_Callback()`:
- 1000 ms: `robot.TIM_1000ms_Alive_PeriodElapsedCallback()` (~~Referee, Manifold, Supercap alive checks~~ currently empty).
- 100 ms: `robot.TIM_100ms_Alive_PeriodElapsedCallback()` (~~DR16, Chassis, Gimbal, Booster, Posture~~ PC + Chassis alive checks).
- ~~100 ms: `robot.TIM_100ms_Calculate_Callback()` (power control PIDs for chassis power limits).~~
- 10 ms: `robot.TIM_10ms_Calculate_PeriodElapsedCallback()` (~~Manifold control + UART send, Supercap send~~ currently empty).
- 2 ms: `robot.TIM_2ms_Calculate_PeriodElapsedCallback()` (Chassis resolution + control loop).
- 1 ms: `robot.TIM_1ms_Calculate_Callback()` (~~status, supercap, chassis, gimbal, booster control, plus gimbal and posture updates~~ PC parse + chassis target update).
- Telemetry: Serialplot writes 6 channels each 5 ms in `Task1ms_TIM5_Callback()` (200 Hz).
- Driver layer each 1 ms: `TIM_1ms_CAN_PeriodElapsedCallback()`, `TIM_1ms_UART_PeriodElapsedCallback()`, `TIM_1ms_IWDG_PeriodElapsedCallback()`.

### Interrupt callbacks
- CAN FIFO callbacks in `drv_can.cpp` dispatch to `Device_CAN1_Callback()` ~~and `Device_CAN2_Callback()`~~.
- UART receive-to-idle callback in `drv_uart.cpp` dispatches to ~~`DR16_UART1_Callback()`, `Manifold_UART3_Callback()`, `Referee_UART6_Callback()`, `Chassis_AHRS_UART7_Callback()`, `Gimbal_AHRS_UART8_Callback()`~~ and now to `PC_UART2_Callback()` (falls through to Serialplot if not a PC frame).
- `Task100us_TIM4_Callback()` is currently empty (stub).

## Current data chain (PC UART2 -> CAN1 -> motors -> telemetry)
1. PC sends a 26-byte frame on UART2: header 0xAC + payload (5 floats: right_x/right_y/left_x/left_y/yaw, uint16 key mask, 2 switch bytes) + 8-bit checksum (sum of payload).
2. UART2 receive-to-idle DMA triggers `PC_UART2_Callback()`; `Class_PC::UART_RxCpltCallback()` parses the frame. Unmatched frames are passed to Serialplot parsing.
3. Each 1 ms, `Class_PC::TIM_1ms_Calculate_PeriodElapsedCallback()` updates key/switch edge states, then `Class_Robot::_Chassis_Control()` maps input to target `vx/vy` (m/s) and `omega` (rad/s) with slope planning.
4. Each 2 ms, `Class_Chassis::Self_Resolution()` computes odom (`vx/vy/omega`) from wheel speeds, then inverse kinematics computes target wheel omegas.
5. `PID_Velocity_X/Y/Omega` outputs are converted to per-wheel target current (with speed correction + resistance compensation).
6. `TIM_1ms_CAN_PeriodElapsedCallback()` sends CAN1 0x200 with 4 wheel currents. Motor feedback 0x201-0x204 updates wheel speed/power estimates.
7. Each 5 ms, Serialplot sends 6 float channels over UART2: target vx/vy/omega and now vx/vy/omega.

## Control logic (operator and subsystem behavior)
### Input sources
- ~~DR16: left stick for chassis translation, yaw channel for chassis rotation, right stick for gimbal.~~
- ~~Mouse and keyboard: gimbal fine aim, chassis WASD, mode toggles.~~
- ~~Manifold: auto aiming target angles and feedforward.~~
- ~~Referee: power, heat, and robot status constraints.~~
- PC UART2 frame: left_x/left_y for chassis translation, yaw for rotation; `tools/pc_control.py` maps WASD to left stick and Q/E to yaw.

### ~~Mode and status control (`Class_Robot::_Status_Control`)~~
~~Key behaviors:~~
- ~~Safety: if DR16 offline or left switch down, control is disabled.~~
- ~~Gyro mode: Q or E sets continuous spin (counterclockwise or clockwise). Releasing returns to follow mode.~~
- ~~Supercap accelerate: Shift enables acceleration, B enables burst acceleration.~~
- ~~Auto aim: right mouse enables Manifold aiming.~~
- ~~Manifold priority: V toggles armor vs rune, long left mouse hold forces armor.~~
- ~~With Ctrl+Shift held:~~
  - ~~Z reset MCU.~~
  - ~~C toggle supercap enable.~~
  - ~~Q toggle self color (also disables referee trust).~~
  - ~~X toggle referee trust.~~
  - ~~A toggle chassis type (HP vs POWER).~~
  - ~~S toggle booster type (BURST vs CD).~~
  - ~~E/D adjust robot level.~~
  - ~~R redraw UI.~~
- ~~Referee online updates self color and robot level from referee ID and level.~~

### Current mode and status control (chassis-only)
- Safety: if PC offline or left switch down, chassis control is disabled.
- Speed boost: Shift increases max chassis speed and omega (see `_Chassis_Control()`).
- No gyro/follow/supercap/referee/manifold modes in current build.

### ~~Supercap control (`Class_Robot::_Supercap_Control`)~~
- ~~Power limit for the supercap is set based on referee power limits or fallback tables.~~
- ~~Buffer energy, energy loop, and power compensation are set every tick.~~
- ~~Supercap is disabled if DR16 is offline, manually disabled, gimbal is offline, referee chassis power is offline, or buffer energy is too low.~~
- ~~Auto restart is allowed once buffer energy recovers above a threshold.~~

### Chassis control (`Class_Robot::_Chassis_Control`)
- ~~Power limit is derived from referee (if trusted) or fallback tables based on robot type and level.~~
- ~~If supercap is enabled and has normal energy, power limit is boosted (burst or normal acceleration).~~
- Power limit is fixed to 45.0f in current code (no referee/supercap inputs).
- PC offline or left switch down disables chassis control.
- Targets:
  - Translation from PC left stick (WASD in `tools/pc_control.py`), rotation from yaw (Q/E in `tools/pc_control.py`).
  - ~~Keyboard WASD adds full speed increments (when Ctrl is not pressed).~~
  - ~~Gyro mode adds constant rotation.~~
  - ~~Follow mode adds PID correction to align chassis yaw with gimbal yaw.~~
  - Yaw sign is inverted in code so Q = CCW and E = CW with the default PC script.
- Slope (ramp) control:
  - X/Y speeds are passed through slope planners using current chassis velocity (chassis frame).
  - Omega uses its own slope planner with chassis omega feedback.
- Chassis targets are set directly in chassis frame ~~after gimbal yaw feedforward compensation~~.

### ~~Gimbal control (`Class_Robot::_Gimbal_Control`)~~
- ~~DR16 offline or left switch down disables gimbal control.~~
- ~~Angle mode is used by default.~~
- ~~Right stick and mouse control yaw and pitch, with feedforward omega.~~
- ~~Auto aim (Manifold) overrides target angles and feedforward when enabled.~~
- ~~Chassis rotation feedforward is subtracted from yaw to maintain stability.~~

### ~~Booster control (`Class_Robot::_Booster_Control`)~~
- ~~A heat detector FSM estimates firing heat from friction wheel current if referee is unavailable.~~
- ~~Heat limits come from referee when trusted, otherwise from local tables.~~
- ~~DR16 offline or left switch down disables booster control.~~
- ~~Trigger logic:~~
  - ~~Right switch or mouse left triggers spot fire.~~
  - ~~Right switch down or long left mouse hold triggers auto fire.~~
  - ~~Referee heat limits adjust the maximum firing frequency.~~

## Chassis kinematics and dynamics
~~The chassis is a 4 wheel swerve drive with steer motors (GM6020) and wheel motors (C620). Key parameters:~~
- ~~Wheel radius: 0.058 m.~~
- ~~Wheel positions: 4 corners at 45, 135, 225, 315 degrees.~~
- ~~Distance to core: 0.207 m for each wheel.~~

Current chassis is a 4 wheel mecanum drive (C620 + M3508):
- Wheel radius: 0.0762 m.
- Half length: 0.1905 m.
- Half width: 0.3175 m.
- Wheel order: FL (ID1/0x201), FR (ID2/0x202), RL (ID3/0x203), RR (ID4/0x204).

### Forward kinematics (self resolution)
~~Computed in `Class_Chassis::Self_Resolution()`:~~
- ~~Vx = sum(omega_wheel * cos(steer_angle) * R) / 4~~
- ~~Vy = sum(omega_wheel * sin(steer_angle) * R) / 4~~
- ~~Omega = sum(omega_wheel * sin(steer_angle - wheel_azimuth) * R / distance) / 4~~
- ~~Pitch/roll from AHRS are used to compute slope direction vector.~~

Current (mecanum, using wheel omegas with direction signs `s_i`):
- Vx = R * (s_fl*w_fl + s_fr*w_fr + s_rl*w_rl + s_rr*w_rr) / 4
- Vy = R * (-s_fl*w_fl + s_fr*w_fr + s_rl*w_rl - s_rr*w_rr) / 4
- Omega = R * (-s_fl*w_fl + s_fr*w_fr - s_rl*w_rl + s_rr*w_rr) / (4 * (L + W))
- Pitch/roll are fixed to 0; slope direction is (0, 0, 1).

### Inverse kinematics
~~Computed in `Class_Chassis::Kinematics_Inverse_Resolution()`:~~
- ~~For each wheel i:~~
  - ~~vxi = Vx - Omega * dist * sin(azimuth_i)~~
  - ~~vyi = Vy + Omega * dist * cos(azimuth_i)~~
  - ~~wheel_speed = sqrt(vxi^2 + vyi^2) / R~~
  - ~~steer_angle = atan2(vyi, vxi)~~
- ~~Nearest transposition: if the steering change is more than 90 degrees, the wheel is flipped by PI and wheel speed sign is inverted to minimize steering rotation.~~

Current (mecanum, no steering):
- w_fl = (Vx - Vy - Omega * (L + W)) / R
- w_fr = (Vx + Vy + Omega * (L + W)) / R
- w_rl = (Vx + Vy - Omega * (L + W)) / R
- w_rr = (Vx - Vy + Omega * (L + W)) / R
  (direction signs are applied later when converting to motor commands)

### Dynamics inversion
~~Computed in `Class_Chassis::Dynamics_Inverse_Resolution()`:~~
- ~~PID outputs for Vx, Vy, Omega are treated as force and torque.~~
- ~~Per wheel force is computed in the wheel frame and converted to current.~~
- ~~Static and dynamic resistance compensation is applied based on wheel speed.~~

Current (mecanum):
- PID outputs for Vx/Vy/Omega are treated as force_x/force_y/torque.
- Per wheel current uses force contribution and speed error: `Target_Wheel_Current[i] = (force term) * R + Wheel_Speed_Limit_Factor * (Target_Wheel_Omega - Now_Omega)`.
- Dynamic resistance compensation is applied around `Wheel_Resistance_Omega_Threshold` using `Dynamic_Resistance_Wheel_Current[]`.
- Wheel direction signs are applied only when sampling `Now_Omega` and when commanding `Set_Target_Current()` so physical wiring differences do not skew control gains.

### Output and power limiting
- `Output_To_Motor()` sets wheel motors to current mode and runs motor PID loops (no steer motors).
- `_Power_Limit_Control()` uses per motor power estimates to scale wheel outputs; `Steer_Factor` remains 1.0 in this build.

## PID logic
### Algorithm (`Class_PID`)
- Error = Target - Now, with a configurable dead zone.
- P term = Kp * error.
- I term:
  - Optional variable speed integration (thresholds A and B).
  - Optional integral separation (only integrate below a threshold).
  - Optional integral clamp (`I_Out_Max`).
- D term:
  - Standard derivative on error, or derivative on measurement when D-first is enabled.
- F term = Kf * (Target - Pre_Target).
- Output is clamped by `Out_Max` when configured.

### Usage in this project
- Chassis: `PID_Velocity_X`, `PID_Velocity_Y`, `PID_Omega` regulate body velocity and yaw rate.
- ~~Chassis follow: `PID_Chassis_Follow` adds yaw correction to keep chassis aligned with gimbal.~~
- ~~Power control: `PID_Supercap_Chassis_Power` and `PID_Referee_Chassis_Power` adjust available chassis power.~~
- Motors: DJI motor drivers use cascaded loops (angle -> omega -> current).
- ~~GM6020 also supports a 2023 current control variant.~~

## Hardware dependencies
### MCU and peripherals
- STM32F427 (from startup and IOC configuration).
- ~~CAN1, CAN2 for motor and supercap buses.~~
- CAN1 for chassis wheel motors (0x201 to 0x204).
- ~~UART1/2/3/6/7/8 with DMA receive-to-idle for DR16, Serialplot, Manifold, Referee, and AHRS sensors.~~
- UART2 with DMA receive-to-idle for PC control input; UART2 IT TX for Serialplot telemetry.
- TIM4/TIM5 as software scheduler.
- IWDG watchdog.
- GPIO and BSP for board power and LEDs.

### External devices (by bus)
- CAN1:
  - ~~Booster driver motor (0x202).~~
  - ~~Booster friction motors (0x203, 0x204).~~
  - ~~Gimbal yaw/pitch motors (0x205, 0x206).~~
  - Chassis wheel motors (C620 + M3508) IDs 0x201 to 0x204.
- ~~CAN2:~~
  - ~~Chassis wheel motors (0x201 to 0x204).~~
  - ~~Chassis steer motors (0x205 to 0x208).~~
  - ~~Supercap (0x030).~~
- ~~UART1: DR16 remote control receiver.~~
- UART2: PC control + Serialplot.
- ~~UART3: Manifold (vision or auto aim compute unit).~~
- ~~UART6: Referee system.~~
- ~~UART7: Chassis AHRS (Wheeltec).~~
- ~~UART8: Gimbal AHRS (WIT).~~

## ~~Controller communication (DR16) - required code path~~
~~Minimum required pieces for DR16 to work:~~
- ~~`UART_Init(&huart1, DR16_UART1_Callback, 36)` in `Task_Init()`.~~
- ~~`drv_uart.cpp` receive-to-idle DMA handler (`HAL_UARTEx_RxEventCallback`) to dispatch the UART1 callback and re-arm DMA.~~
- ~~`DR16_UART1_Callback()` to call `Class_DR16::UART_RxCpltCallback()`.~~
- ~~`Class_DR16` parsing and its `TIM_100ms_Alive_PeriodElapsedCallback()` and `TIM_1ms_Calculate_PeriodElapsedCallback()` for status and edge detection.~~
- ~~Scheduler path from `Task1ms_TIM5_Callback()` so the above timers run.~~

## Controller communication (PC UART2) - required code path
Minimum required pieces for PC control to work (UART2 @ 115200 baud, 8-N-1):
- `UART_Init(&huart2, PC_UART2_Callback, SERIALPLOT_RX_VARIABLE_ASSIGNMENT_MAX_LENGTH)` in `Task_Init()`.
- `drv_uart.cpp` receive-to-idle DMA handler (`HAL_UARTEx_RxEventCallback`) dispatches UART2 to `PC_UART2_Callback()` and re-arms DMA.
- `PC_UART2_Callback()` calls `Class_PC::UART_RxCpltCallback()`; if parsing fails, it forwards to Serialplot.
- `Class_PC::Parse_Frame()` validates header 0xAC + checksum and unpacks 5 floats + key mask + switches.
- `Class_PC::TIM_100ms_Alive_PeriodElapsedCallback()` and `Class_PC::TIM_1ms_Calculate_PeriodElapsedCallback()` run via `Task1ms_TIM5_Callback()`.

## Callable APIs (high level)
This is a condensed list of the most relevant APIs used by control logic:

- `Class_Robot` (in `ita_robot.h`)
  - `Init()`, `Loop()`
  - `TIM_1000ms_Alive_PeriodElapsedCallback()`
  - `TIM_100ms_Alive_PeriodElapsedCallback()`
  - ~~`TIM_100ms_Calculate_Callback()`~~
  - `TIM_10ms_Calculate_PeriodElapsedCallback()`
  - `TIM_2ms_Calculate_PeriodElapsedCallback()`
  - `TIM_1ms_Calculate_Callback()`

- `Class_Chassis` (in `crt_chassis.h`)
  - `Init()`
  - `Set_Chassis_Control_Type()`
  - `Set_Target_Velocity_X()`, `Set_Target_Velocity_Y()`, `Set_Target_Omega()`
  - `Set_Power_Limit_Max()`
  - `TIM_2ms_Resolution_PeriodElapsedCallback()`
  - `TIM_2ms_Control_PeriodElapsedCallback()`
  - `Get_Now_Velocity_X()`, `Get_Now_Velocity_Y()`, `Get_Now_Omega()`

- `Class_PC` (in `dvc_pc.h`)
  - `Init()`
  - `UART_RxCpltCallback()`
  - `TIM_100ms_Alive_PeriodElapsedCallback()`
  - `TIM_1ms_Calculate_PeriodElapsedCallback()`
  - `Get_*()` accessors for sticks, yaw, switches, and keyboard mask

- ~~`Class_Gimbal` (in `crt_gimbal.h`)~~
  - ~~`Init()`~~
  - ~~`Set_Gimbal_Control_Type()`~~
  - ~~`Set_Target_Yaw_Angle()`, `Set_Target_Pitch_Angle()`~~
  - ~~`TIM_1ms_Resolution_PeriodElapsedCallback()`~~
  - ~~`TIM_1ms_Control_PeriodElapsedCallback()`~~

- ~~`Class_Booster` (in `crt_booster.h`)~~
  - ~~`Init()`~~
  - ~~`Set_Booster_Control_Type()`~~
  - ~~`Set_Friction_Omega()` and fire mode setters~~
  - ~~`TIM_1ms_Calculate_PeriodElapsedCallback()`~~

- ~~`Class_DR16` (in `dvc_dr16.h`)~~
  - ~~`Init()`~~
  - ~~`UART_RxCpltCallback()`~~
  - ~~`TIM_100ms_Alive_PeriodElapsedCallback()`~~
  - ~~`TIM_1ms_Calculate_PeriodElapsedCallback()`~~
  - ~~`Get_*()` accessors for sticks, switches, mouse, keys, yaw~~

- `Class_PID` (in `alg_pid.h`)
  - `Init()`, `Set_Target()`, `Set_Now()`, `TIM_Calculate_PeriodElapsedCallback()`
  - `Set_K_P/I/D/F()`, `Set_I_Out_Max()`, `Set_Out_Max()`
  - `Get_Out()`

## Executable vs separable code
### Executable (tied to runtime scheduling and hardware)
- `test/Core/Src/main.c`
- `test/User_File/5_Task/tsk_config_and_callback.cpp`
- `test/User_File/4_Interaction/ita_robot.cpp`
- `test/User_File/3_Chariot/1_Module/*` ~~and `3_Chariot/2_Posture/*`~~
- Hardware drivers in `test/User_File/1_Middleware/1_Driver/*` (CAN, UART, TIM, WDG, BSP)

### Separable (reusable or portable modules)
- Algorithms: `test/User_File/1_Middleware/2_Algorithm/*` (PID, Slope, Filter, Timer, Queue).
- Device drivers: `test/User_File/2_Device/*` can be reused with different projects if the bus layer is adapted.
- UI / Serialplot: optional instrumentation that can be removed without affecting core control.

## Notes
- `Task100us_TIM4_Callback()` is empty, so TIM4 is not doing work yet.
- ~~`Dynamics_Inverse_Resolution()` has a TODO comment for slope and pressure effects.~~
- ~~Some posture math for Eigen matrices is currently commented out.~~
- IMU data is not used; pitch/roll are fixed to 0 and slope vector is (0, 0, 1).

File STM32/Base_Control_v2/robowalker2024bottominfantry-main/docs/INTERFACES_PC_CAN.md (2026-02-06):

# STM32 ⇄ Host (PC/Jetson) Interface Specification

This document captures the external I/O contracts used by the RoboWalker 2024 bottom infantry firmware: the UART2 “PC control” link and the CAN1 motor bus. It is derived from the current `test` target (January 2026 snapshot).

## UART2 (PC control + telemetry)
| Item | Value |
| --- | --- |
| Port | USART2 (STM32F427, PD5 TX / PD6 RX) |
| Baud | 115 200 bps |
| Framing | 8 data bits, no parity, 1 stop bit (8‑N‑1) |
| Flow control | None |
| Driver | DMA receive-to-idle, interrupt-driven TX |

Two logical streams share this link:

1. **PC → STM32 control frame** (`tools/pc_control.py`, Jetson/PC host)
2. **STM32 → PC telemetry frame** (Serialplot-compatible)

### PC → STM32 frame

```
Offset  Size  Type     Name
0       1     uint8    Header (0xAC)
1       4     float    Right stick X  (unused, reserved)
5       4     float    Right stick Y  (unused, reserved)
9       4     float    Left stick X   (strafe, -1..1)
13      4     float    Left stick Y   (forward, -1..1)
17      4     float    Yaw            (spin, -1..1)
21      2     uint16   Keyboard mask  (bitfield, see below)
23      1     uint8    Left switch    (DR16 encoding: 1=UP, 2=MID, 3=DOWN)
24      1     uint8    Right switch   (same as left)
25      1     uint8    Checksum = sum(bytes[1..24]) & 0xFF
```

- Total size: 26 bytes. Any other size is discarded.
- Frame rate: default 50 Hz (`--rate` in `pc_control.py`).
- Default host settings: COM14, 115 200 bps, overridable via CLI flags.

Keyboard mask bits follow the DR16 convention used in `dvc_pc.h`:

| Bit | Key | In-firmware action (Jan 2026 build) |
| --- | --- | --- |
|0|`W`|Set left stick Y = +1 ⇒ chassis forward|
|1|`S`|Set left stick Y = −1 ⇒ chassis reverse|
|2|`A`|Set left stick X = −1 ⇒ strafe left|
|3|`D`|Set left stick X = +1 ⇒ strafe right|
|4|`Shift`|Speed boost (`_Chassis_Control` raises velocity/omega limits)|
|5|`Ctrl`|Reserved (parsed but unused)|
|6|`Q`|Yaw command −1 ⇒ rotate CCW|
|7|`E`|Yaw command +1 ⇒ rotate CW|
|8|`R`|Reserved|
|9|`F`|Reserved|
|10|`G`|Reserved|
|11|`Z`|Reserved|
|12|`X`|Reserved|
|13|`C`|Reserved|
|14|`V`|Reserved|
|15|`B`|Reserved|

> Reserved keys still travel inside the frame (and keep DR16-compatible semantics) but the current firmware does not act on them. They remain available for future mode toggles (e.g., gyroscope, supercap, booster) without breaking the protocol.

**Host implementation tips**

- When integrating with ROS 2 on Jetson, reuse the frame format above—only the transport layer changes (wrap `pyserial`/`asio` inside a ROS 2 node).
- Keep the UART window focused (if using `pynput`) so key events propagate; otherwise no bits are set.
- Left switch down (`value == 3`) or loss of frames for >100 ms disables the chassis (`Chassis_Control_Type_DISABLE`).

### STM32 → PC telemetry frame (Serialplot)

The firmware reuses the Serialplot transport in `dvc_serialplot.cpp`. Every 5 ms (200 Hz) the following 6 floats are sent (little-endian):

| Channel | Signal |
| --- | --- |
|0|Target vx (m/s)|
|1|Target vy (m/s)|
|2|Target omega (rad/s)|
|3|Measured vx (m/s)|
|4|Measured vy (m/s)|
|5|Measured omega (rad/s)|

Current firmware frame format on UART2 TX:

- Header: `0xAB`
- Payload: 6 x `float32` (24 bytes)
- Checksum: 8-bit sum over payload (1 byte)

Total frame size: 26 bytes, i.e. about 52 kbps at 200 Hz (safe margin at 115200 bps). Hosts that don’t need telemetry may ignore UART2 TX entirely.

## CAN1 (chassis motors)

| Item | Value |
| --- | --- |
| Bus | CAN1 (1 Mbps, normal mode) |
| Command ID | 0x200 |
| Feedback IDs | 0x201 (FL), 0x202 (FR), 0x203 (RL), 0x204 (RR) |
| Motor type | DJI C620 + M3508 |

### STM32 → Motors (ID 0x200)

```
Byte 0~1 : Wheel FL target current (int16, big-endian)
Byte 2~3 : Wheel FR target current
Byte 4~5 : Wheel RL target current
Byte 6~7 : Wheel RR target current
```

- Units follow DJI ESC scaling (range ±16384 ≈ ±20 A).
- Sign already accounts for wiring via `Wheel_Direction`, so FR/RR currents may be negative for forward motion.
- Frames are refreshed every 1 ms (TIM5 scheduler).

### Motors → STM32 (IDs 0x201–0x204)

Each M3508/C620 reports an 8-byte status frame:

```
Byte 0~1 : Encoder (0..8191)
Byte 2~3 : Speed (int16, ±RPM)
Byte 4~5 : Current (int16, raw ADC units)
Byte 6   : Temperature (°C)
Byte 7   : Reserved
```

`dvc_motor_dji.cpp` converts these into angle (rad), omega (rad/s), current (A), and estimates instant power for power limiting. Encoder and speed values are multiplied by the wheel’s direction sign before feeding odometry, so the host does not need to compensate.

## Summary
- UART2 provides the primary host control ingress. Maintain the 26-byte frame and checksum if replacing the PC tool with Jetson/ROS 2.
- CAN1 drives the four chassis motors with ID 0x200 and reads back motor statuses via 0x201–0x204.
- Directional mismatches are abstracted in firmware (`Wheel_Direction`), so external tools can treat all wheels as having the same forward convention.

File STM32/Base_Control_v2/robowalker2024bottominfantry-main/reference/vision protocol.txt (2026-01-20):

// 帧头控制数据, 2B
uint8_t Frame_Header;
Enum_Manifold_Aiming_Priority : uint8_t Aiming_Priority;

// 云台电机数据, 16B
float Gimbal_Motor_Angle_Yaw;
float Gimbal_Motor_Angle_Pitch;
float Gimbal_Motor_Omega_Yaw;
float Gimbal_Motor_Omega_Pitch;

// 云台相对Odom数据, 20B
float Gimbal_Angle_Yaw;
float Gimbal_Angle_Pitch;
float Gimbal_Angle_Roll;
float Gimbal_Velocity_X;
float Gimbal_Velocity_Y;

// 云台IMU源数据, 24B
float Gimbal_IMU_Omega_X;
float Gimbal_IMU_Omega_Y;
float Gimbal_IMU_Omega_Z;
float Gimbal_IMU_Accel_X;
float Gimbal_IMU_Accel_Y;
float Gimbal_IMU_Accel_Z;

// 帧尾, 1B
uint8_t Frame_Rear;

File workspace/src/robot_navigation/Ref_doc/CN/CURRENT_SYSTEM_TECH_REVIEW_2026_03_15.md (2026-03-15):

# 当前系统技术审查

日期：2026-03-15

范围：
- 本文描述的是 2026-03-15 这次代码快照下仓库的当前实现状态。
- 本文按“代码真实行为”写，不按“原始设计意图”写。
- 覆盖导航栈、semantic map、任务执行链路，以及当前前端/后端围绕地图与 SLAM 页的连接关系。

本文可以看作对 `Ref_doc/CN` 与 `Ref_doc/EN` 里旧导航 review 的当前态补充。旧文档里很多分析仍有参考价值，但本文优先反映现有代码到底在做什么。

## 0. 执行摘要

当前系统已经不只是一个 ROS 导航工程，而是一套多层系统：

- 以 SICK PicoScan、Cartographer、EKF、Nav2 为核心的 ROS 2 导航与定位栈。
- 一层独立的 semantic overlay，既在 ROS 里存在，也在员工网页 UI 里存在。
- 一个 PostgreSQL + Node.js 后端，负责库存、员工认证、订单接口、semantic map 接口和 semantic map 版本历史。
- 一个基于 Vue 的员工端 dashboard，其中：
  - `Store Map` 是自定义可编辑 semantic map 页面。
  - `SLAM Map` 是把 vendored 的 ROS Web GUI 工具嵌进 iframe 的外层壳。

当前最关键的系统事实如下：

- mapping 和 localization 都是基于 PointCloud2 的 Cartographer 管线。
- localization 用的是 Cartographer localization + static map server，不是 AMCL。
- Nav2 当前主栈是 `SmacPlanner2D + MPPIController`，并且启用了 omni motion model。
- semantic map 当前在线主源仍然是 YAML。
- PostgreSQL 里的 semantic version 表目前是版本快照，不是主读源。
- `Store Map` 页面可以编辑 semantic map，并同时保存到 YAML 和数据库版本表。
- `SLAM Map` 页面不是自绘 canvas，而是一个外层壳，里面嵌的是 vendored `ros_web_gui_app`，由 iframe 内部直接连 `rosbridge`。

当前已经能工作，但“设计目标”和“当前真实行为”之间还有几个明显断点：

- 默认 BT executor 只轮询 customer order，不轮询 employee restock。
- customer 树当前只做导航，不改库存。
- restock 树当前反而调用了“decrement inventory”接口，语义上是反的。
- robot status 页面仍然是后端占位数据，不是 ROS 实时状态。
- 嵌入式 SLAM 页面必须额外跑 `rosbridge_server`，不会经过 Node 后端转发。

## 1. 代码边界与当前相关包

### 1.1 ROS 包

当前 `workspace/src` 里与本 review 直接相关的包：

- `robot_navigation`
  - launch 组合
  - Cartographer 配置
  - Nav2 参数
  - serial bridge
  - base-link crop filter
  - semantic map server
  - `nav_assistant` CLI
- `robot_task_manager`
  - blackboard
  - BT executor
  - BT nodes
  - customer / restock 树
  - 另一套 ViperX BT 路径
- `robot_interfaces`
  - `Order`、`OrderItem`
  - `NewOrder.srv`
  - `ResolveSemanticTarget.srv`
  - `MoveRack.action`
  - `PickArm.action`
- `robot_manipulation`
  - VX300 MoveIt launch
  - `pick_arm` action server

### 1.2 Web / backend 部分

当前 Web / backend 相关目录：

- `order-api-postgre`
  - Express 后端
  - PostgreSQL 接入
  - semantic map 文件解析与保存逻辑
- `order-api-postgre/fleet-manager`
  - 员工端 Vue dashboard
  - Store Map 页面
  - SLAM 页面外层壳
- `third_party/ros_web_gui_app`
  - 从 `StarLionJiang/ros_web_gui_app` vendored 下来的源码
  - 已做英文 UI 文案适配，用于嵌入式 SLAM 页面

### 1.3 地图资产与 semantic 资产

当前地图资产：

- `Maps/testmapMain.pbstream`
- `Maps/testmapMain.yaml`
- `Maps/testmapMain.pgm`

当前 semantic overlay 资产：

- `workspace/src/robot_navigation/config/semantic_map_testmapMain.yaml`

当前重要地图事实：

- 地图名：`testmapMain`
- 地图分辨率：`0.03 m/pixel`
- 地图在 `map` 坐标系里的 origin：`[-2.797711, -10.398200, 0.0]`
- semantic map id：`testmapMain`
- semantic home anchor 当前配置为 `(0.0, 0.0, 0.0)`

## 2. 当前导航栈

### 2.1 Mapping 栈

当前 mapping 启动入口：

- `ros2 launch robot_navigation slam_mapping_stack.launch.py`
- 或 `ros2 run robot_navigation nav_assistant mapping-stack`

当前 mapping 栈组成：

- SICK PicoScan 驱动 `sick_generic_caller`
- 静态 TF：`base_link -> lidar_link`
- 静态 TF：`lidar_link -> imu_link`
- `base_link_crop_filter`
- Cartographer mapping
- serial bridge
- 可选 EKF
- 可选 ultrasonic collision launch
- 可选 RViz

当前 mapping 传感器链路：

- LiDAR 原始点云：`/cloud_all_fields_fullframe`
- 给 Cartographer 的裁剪后点云：`/cloud_all_fields_fullframe_filtered`
- IMU：`/sick_scansegment_xd/imu`

当前 mapping 行为：

- Cartographer mapping 使用的是裁剪后的点云。
- Cartographer 通过 `cartographer_occupancy_grid_node` 发布 occupancy grid。
- crop filter 在 mapping 里默认开启。
- crop filter 的主要作用是把机器人车体自击中的点从 Cartographer 输入里去掉。

当前 Cartographer mapping 配置事实：

- `tracking_frame = "imu_link"`
- `published_frame = "base_link"`
- `odom_frame = "odom"`
- `use_odometry = true`
- `use_imu_data = true`
- `num_point_clouds = 1`
- `num_laser_scans = 0`
- `publish_frame_projected_to_2d = true`

这说明当前 mapping 不是 LaserScan 主链路，而是 PointCloud2 + IMU + odom 主链路。

### 2.2 Localization + Nav2 栈

当前 localization 启动入口：

- `ros2 launch robot_navigation nav2_localization_stack.launch.py`
- 或 `ros2 run robot_navigation nav_assistant localization-stack --map-name testmapMain`

当前 localization 栈组成：

- SICK PicoScan 驱动
- 静态 TF
- serial bridge
- 可选 EKF
- 可选 crop filter，默认关闭
- Cartographer localization，加载 `pbstream`
- `nav2_map_server` 提供 `testmapMain.yaml`
- map server lifecycle manager
- 2 秒延迟后启动 Nav2 bringup
- 可选 Nav2 RViz
- semantic map server，默认开启

当前 localization 的重要行为：

- Cartographer localization 加载保存下来的 `pbstream` 状态。
- localization 模式下 `publish_occupancy_grid=false`。
- localization 模式里的 `/map` 来自 `nav2_map_server`，不是 Cartographer。
- Cartographer 在这里主要负责 localization / TF；static occupancy grid 由导出的 yaml / pgm 提供。

这点是当前结构里的关键区别：

- mapping 模式：Cartographer 生成地图
- localization 模式：Cartographer 负责定位，`map_server` 负责静态地图

### 2.3 EKF 路径

当前 EKF 配置：

- 输入 odom：`/odom_raw`
- 输入 IMU：`/sick_scansegment_xd/imu`
- 输出：`/odom`
- `publish_tf: false`
- `world_frame: odom`
- `two_d_mode: true`

当前实际链路：

`STM32 telemetry -> nav2_serial_bridge -> /odom_raw`

`/odom_raw + /sick_scansegment_xd/imu -> robot_localization EKF -> /odom`

### 2.4 Nav2 当前技术栈

当前 Nav2 参数文件：

- `workspace/src/robot_navigation/config/nav2_params_smac_mppi_omni.yaml`

当前 active planner / controller：

- planner：`nav2_smac_planner/SmacPlanner2D`
- controller：`nav2_mppi_controller::MPPIController`
- motion model：`Omni`

当前 costmap 行为：

- local costmap：
  - 在 `odom` 坐标系滚动窗口
  - `VoxelLayer + InflationLayer`
  - 点云源：`/cloud_all_fields_fullframe`
- global costmap：
  - 在 `map` 坐标系
  - `StaticLayer + ObstacleLayer + InflationLayer`
  - 障碍物源：`/cloud_all_fields_fullframe`

这里有一个当前实现层面的重要事实：

- Cartographer 在 mapping / localization 里吃的是裁剪后的 cloud。
- Nav2 costmap 目前仍然用的是原始 cloud topic，不是裁剪后的 cloud。
- 也就是说 crop filter 现在主要保护 Cartographer 输入，不直接保护 Nav2 obstacle layer。

### 2.5 Serial bridge 与控制链路

当前 serial bridge：

- 节点：`robot_navigation/nav2_serial_bridge.py`
- 作用：
  - 把 `/cmd_vel` 类命令经串口发给 STM32
  - 把 telemetry 解码成 odometry
  - telemetry 断流时可选 fallback odom

当前默认桥接命令 topic：

- mapping 栈：`["/cmd_vel", "/cmd_vel_nav", "/cmd_vel_smoothed"]`
- localization 栈：`["/cmd_vel"]`

当前 command authority 事实：

- 还没有真正实现 `cmd_vel` 仲裁器
- 多个命令源之间仍然是简单订阅
- 旧规划文档里提到的 arbiter 仍然没有进入当前主代码路径

## 3. 当前 Semantic Map 栈

### 3.1 Semantic map 表示方式

当前 semantic map 是一份手工维护的 YAML overlay，不是从 RViz 或 SLAM 自动提取出来的。

当前文件：

- `workspace/src/robot_navigation/config/semantic_map_testmapMain.yaml`

当前结构：

- `map`
- `anchors`
- `racks`
- `slots`

当前 semantic 内容：

- anchors：
  - `home`
  - `drinks_anchor`
  - `fruits_anchor`
  - `snacks_anchor`
- racks：
  - 每个 anchor 区域对应一组 rack
- slots：
  - 当前有 7 个 slot
  - 绑定到 seeded inventory 里的 product id 1 到 7

当前必须明确的事实：

- 这份 semantic map 是人工标注的
- 不是从 RViz 自动生成
- 当前也不是从 PostgreSQL 直接读出来当主源
- 现在它是围绕 seeded store example 写的一份示例化语义图

### 3.2 ROS semantic map server

当前 semantic ROS 节点：

- `robot_navigation/semantic_map_server.py`

当前职责：

- 读取 semantic YAML
- 发布 marker overlay
- 提供 semantic resolve service

当前接口：

- markers：`/semantic_map/markers`
- service：`/semantic_map/resolve_target`

当前解析顺序：

1. 显式 `slot_id`
2. 显式 `anchor_id`
3. `product_id`
4. `product_name`

### 3.3 Semantic map 在 Web 里的实现方式

当前 semantic map 已经能在员工 UI 里显示和编辑，但 Web 路径和 ROS 路径不是一回事。

当前 backend semantic 行为：

- 在线读取 YAML
- 用 PostgreSQL 的 `inventory` 信息 enrich slot 产品信息
- 通过 REST 暴露 bundle
- 保存编辑结果回 YAML
- 每次保存同时写数据库版本快照

当前最关键的实现事实：

- YAML 仍然是在线主源
- `semantic_map_versions` 目前只是版本历史
- 直接改数据库不会改变当前前端读到的 live semantic map，除非 YAML 也一起改

## 4. 当前任务执行与 BT 链路

### 4.1 默认 BT executor

当前默认 executor：

- `workspace/src/robot_task_manager/robot_task_manager/bt_executor.py`

当前行为：

- 提供 `/order/new` service
- 每秒轮询一次 Node backend
- 只轮询 `GET /api/order/latest`
- 根据 `order.role` 构造 customer 或 employee 树
- 以 10 Hz tick BT

当前 order intake 来源：

- 自动轮询只支持 `order_id` 里的 customer order
- 员工端提交到 `restock_id` 的 restock request 不会被默认 executor 拉取

这是一条非常重要的当前限制：员工 UI 可以提交 restock，但默认 executor 不会自动消费它。

### 4.2 Blackboard 状态

当前 blackboard 已包含：

- 订单上下文
- 当前 item 上下文
- arm 占位字段
- rack 状态
- navigation goal
- semantic 相关字段

当前新增的 semantic 字段包括：

- `slot_id`
- `anchor_id`
- `rack_id`
- `semantic_id`
- `semantic_target_label`
- `nav_goal_source`
- `nav_goal`
- `home_goal`
- `shelf_pose`

当前配置的 home navigation goal：

- `(0.0, 0.0, 0.0)`

但这里要注意：

- 这是 blackboard 默认值
- 不是说 localization 会自动把机器人初始化在 `(0,0,0)`

### 4.3 Customer 树

当前默认 customer 树流程：

1. `SetCurrentItem`
2. `ResolveCurrentItemSemanticTarget`
3. `NavigateToGoalPose(nav_goal)`
4. 对每个 item 重复
5. `SetHome`
6. `NavigateToGoalPose(nav_goal)`

当前真实行为：

- 先用 semantic map 解析目标
- semantic 解析失败时回退到 legacy `x/y/z`
- 当前不执行 manipulation
- 当前不调用 `ChangeInventory`

所以当前 customer 树本质上是一个“导航到点位再回 home”的树。

### 4.4 Restock 树

当前默认 restock 树流程：

1. `SetCurrentItem`
2. `ResolveCurrentItemSemanticTarget`
3. `NavigateToGoalPose(nav_goal)`
4. `ChangeInventory`
5. 重复
6. `SetHome`
7. `NavigateToGoalPose(nav_goal)`

当前真实行为：

- manipulation 相关步骤仍大量注释掉
- inventory 更新是打开的

但当前代码里有一个非常关键的真实问题：

- `ChangeInventory` 无论什么 mode 都调用 `/api/inventory/decrement`
- 它不会按 `mode` 分支
- 所以当前 restock 树实际上是在“减库存”，不是“加库存”

这不是设计推测，而是当前代码的真实行为。

### 4.5 Semantic target 节点

当前 semantic BT 节点：

- `ResolveCurrentItemSemanticTarget`

当前行为：

- 从当前 item 里取 `product_id` 和 `name`
- 调 `/semantic_map/resolve_target`
- 把解析结果写回 blackboard
- 如果服务不可用或找不到，就回退到 legacy 坐标继续走

当前 fallback 路径：

- `SetCurrentItem` 会先写入：
  - `bb.nav_goal = (x, y, 0.0)`，来自 legacy order item 字段
  - `bb.rack_goal = z`
- semantic 成功时再覆盖这些值
- semantic 失败时就继续用这些 legacy 值

### 4.6 Nav2 动作叶子

当前导航 BT 叶子：

- `NavigateToGoalPose`

当前行为：

- 从 `bb.nav_goal` 读目标
- 支持 tuple / dict / PoseStamped
- 调 Nav2 `NavigateToPose`
- 已经不再用旧的硬编码 `(2.0, 0.0)` demo 点

### 4.7 完成回报行为

当前 BT 完成时：

- executor 会向 `/api/order/complete` 上报完成状态

当前 backend 的 `/api/order/complete` 行为：

- 只更新 `order_id` 表

因此：

- customer 完成回写在表层面是成立的
- employee / restock 就算通过别的方式塞进树里，默认完成回报也没有对应 `restock_id` 更新路径

### 4.8 另一条 ViperX 路径

当前代码里还存在一条 ViperX 专用 BT 路径：

- `bt_executor_viperx.py`
- `trees/customer_viperx.py`
- `trees/restock_viperx.py`
- `bt_nodes/viperx_nodes.py`

当前状态：

- 代码存在
- 但不是上面那条默认执行链的主路径
- 仍然大量注释或未完成
- 当前也没有与员工 UI 主流程打通

## 5. 当前机械臂执行栈

仓库现在已经有比较真实的 VX300 侧 manipulation backend，但默认 BT 链还没有把它完整接起来。

当前已经实现的 manipulation backend：

- `robot_manipulation/src/arm_controller.cpp`
- launch：`robot_manipulation/launch/vx300_moveit.launch.py`
- action：`robot_interfaces/action/PickArm.action`

当前 manipulation backend 能力：

- MoveIt 规划
- `pick_arm` action server
- pre-grasp / approach / retreat
- 可选 Cartesian approach

当前 BT 侧状态：

- generic arm BT node 仍是 TODO
- 默认 customer / restock 树里大部分 manipulation 步骤仍然注释掉

也就是说当前仓库里已经出现了：

- 比之前更真实的 arm backend
- 但还没有完整接到默认业务执行链上的 end-to-end manipulation

## 6. 后端与数据库审查

### 6.1 Backend 结构

当前 backend：

- Express
- body-parser
- cors
- PostgreSQL via `pg`
- semantic map 文件逻辑在 `semantic_map.js`

当前 backend 启动时会做：

- 如果没有 `semantic_map_versions` 就创建
- 把旧的 `testmapMain_v1` 这类 semantic id 归一化到 `testmapMain`
- 如果版本历史为空，就从当前 YAML bootstrap 一条版本快照
- 最后监听 `3000` 端口

### 6.2 当前数据库模型

当前 `001_schema.sql` 里的表：

- `customer`
- `employee`
- `inventory`
- `order_id`
- `restock_id`
- `semantic_map_versions`

当前数据库层面的重要现实：

- `inventory` 里仍然有 legacy `x`, `y`, `z`
- customer order 仍会把这些 legacy 位置字段固化进 order JSON
- semantic map 还没有被完全拆成关系型表（rack / slot / placement 等）
- semantic history 当前是 snapshot 存储，不是结构化 semantic entity 存储

### 6.3 当前 semantic map API 行为

当前 semantic 相关接口：

- `GET /api/maps/base/:mapName.pgm`
- `GET /api/maps/semantic/current`
- `PUT /api/maps/semantic/current`

当前认证要求：

- semantic 接口需要 employee auth
- base-map 文件接口不强制 auth

当前 `GET /api/maps/semantic/current` 的行为：

- 从磁盘读取 YAML bundle
- 从 `Maps/testmapMain.yaml` 读取 static map 元数据
- 从 `Maps/testmapMain.pgm` 解析宽高
- 从 `semantic_map_versions` 里附上最新版本信息
- 用 `inventory` 给 slot 的 `product_ids` 做 enrich
- 返回 enriched JSON bundle

当前 `PUT /api/maps/semantic/current` 的行为：

- 接收 Store Map UI 发来的 bundle
- 先保存 YAML
- 再写数据库版本快照
- 如果 DB 写失败，就把旧 YAML 回滚回去

这段 rollback 很重要：当前实现至少在 UI save 这条链路上尽量保证 YAML 和 DB version history 一致。

### 6.4 Auth 与 session 模型

当前 employee auth 流程：

- `POST /api/employee/auth/login`
- 从数据库读取明文密码并比较
- 返回 bearer token
- token 保存在内存 session map 里，TTL 12 小时

当前限制：

- token 只存在进程内存里
- backend 重启后 session 全失效
- 当前 schema 与 seed data 里的密码还是明文

### 6.5 Order 与 restock 接口

当前机器人执行链实际使用的 order 接口：

- `GET /api/order/latest`
- `POST /api/order/ack`
- `POST /api/order/complete`

当前行为：

- 这些接口只围绕 `order_id`
- 没有一条对等的自动 fetch / ack / complete 路径给 `restock_id`

当前员工 UI 使用的 restock 接口：

- `POST /api/employee/restock/submit`

当前行为：

- 往 `restock_id` 表插记录
- 但没有打到默认 executor 的轮询链路里

所以当前 employee restock dashboard 和默认 robot polling path 仍然没有真正打通。

### 6.6 占位 robot status

当前 robot status 接口：

- `GET /api/employee/robot/status`

当前行为：

- 返回三台硬编码机器人
- 如果 semantic map 里有对应 anchor，就用 semantic anchor pose 作为展示位置
- 不订阅 ROS
- 只是 dashboard 的占位数据源

## 7. 前端审查与前后端连接关系

### 7.1 前端结构

当前员工 dashboard：

- Vue 3
- Vue Router
- Vite

当前受保护路由：

- `/app/inventory-report`
- `/app/location-map`
- `/app/slam-map`
- `/app/robot-status`
- `/app/restock`
- `/app/employee-accounts`

当前 auth guard：

- 检查 `localStorage` 里的 `fleet_token`

### 7.2 登录流

当前登录流程：

1. 员工输入 `employee_ID` 和 password
2. 前端调用 `POST /api/employee/auth/login`
3. token 与员工信息写入 `localStorage`
4. router 跳到 `/app/inventory-report`

### 7.3 Inventory report 页面

当前页面：

- `InventoryReportView.vue`

当前 backend contract：

- `GET /api/employee/inventory/report`

当前行为：

- 渲染 summary cards
- 渲染 category breakdown
- 渲染 inventory 明细表
- 明细表里仍然直接显示 legacy `x/y/z`

这说明当前 UI 层仍然同时暴露着旧位置模型和新 semantic 模型。

### 7.4 Store Map 页面

当前页面：

- `LocationMapView.vue`

当前绘图组件：

- `SemanticMapCanvas.vue`

当前行为：

- 从 backend 拉 semantic map bundle
- 解析并渲染底图 PGM
- 自动 fit 到内容范围
- 支持 zoom / pan
- 支持 edit mode
- 支持拖拽 anchor / rack / slot
- 支持手工数值编辑 pose
- 支持保存

当前 save flow：

1. 员工登录拿到 bearer token
2. 页面调用 `GET /api/maps/semantic/current`
3. backend 返回基于 YAML 的 bundle，并附上 DB version
4. 用户在页面本地编辑 geometry
5. 页面调用 `PUT /api/maps/semantic/current`
6. backend 写 YAML，并插入 semantic version 快照
7. 页面重新加载保存后的 bundle，并显示新的版本号

当前 Store Map 数据真相：

- 在线 geometry 主源：YAML
- 版本历史主源：PostgreSQL

### 7.5 SLAM 页面

当前页面：

- `SlamMapView.vue`

当前实现：

- 不是 Foxglove
- 也不是之前那套自绘 `/map + /tf` canvas
- 现在是一个 iframe 外层壳

当前嵌入应用来源：

- vendored fork：`third_party/ros_web_gui_app`
- 源仓库记录为：`https://github.com/StarLionJiang/ros_web_gui_app`

当前运行模型：

- 主 Vue app 提供 `/embedded/ros-web-gui/index.html`
- iframe 加载这个嵌入应用
- 嵌入应用自己管理 `rosbridge` websocket 连接
- 页面默认展示的 bridge 地址是 `ws://<host>:9090`

当前直接后果：

- Node backend 不在 live SLAM transport path 里
- SLAM 页不会通过 Express 代理 ROS topic
- live ROS visualization 依赖单独运行的 `rosbridge_server`

### 7.6 Robot status 页面

当前页面：

- `RobotStatusView.vue`

当前 backend contract：

- `GET /api/employee/robot/status`

当前行为：

- 只显示 dashboard cards
- 没有 live ROS 订阅
- 状态来源是 backend 生成的 placeholder 数据

### 7.7 Restock 与 accounts 页面

当前 restock 页面：

- 从 `GET /api/employee/inventory/options` 拉产品列表
- 调 `POST /api/employee/restock/submit` 提交

当前 employee accounts 页面：

- 从 `GET /api/employee/accounts` 读
- 调 `POST /api/employee/accounts/create` 写

这些页面和 backend 是连通的，但和 ROS 执行链还没有深度打通。

## 8. 信息流审查

### 8.1 传感器到地图

当前 mapping 信息流：

`SICK PicoScan point cloud -> /cloud_all_fields_fullframe`

`/cloud_all_fields_fullframe -> base_link_crop_filter -> /cloud_all_fields_fullframe_filtered`

`/cloud_all_fields_fullframe_filtered + /sick_scansegment_xd/imu + /odom -> Cartographer mapping`

`Cartographer -> live occupancy grid -> mapping visualization/export`

### 8.2 定位到规划执行

当前 localization 信息流：

`STM32 telemetry -> nav2_serial_bridge -> /odom_raw`

`/odom_raw + IMU -> EKF -> /odom`

`point cloud + IMU + /odom + pbstream -> Cartographer localization`

`map_server -> /map`

`Nav2 planner/controller -> NavigateToPose action execution`

### 8.3 Customer order 到机器人

当前 customer 信息流：

`customer order 写入 order_id`

`BT executor 轮询 /api/order/latest`

`backend 返回 items，里面带 legacy x/y/z 与 product metadata`

`BT 把 JSON 转成 Order / OrderItem`

`SetCurrentItem 先写 legacy nav goal`

`ResolveCurrentItemSemanticTarget 再尝试做 product -> slot / service pose 解析`

`NavigateToGoalPose 发 Nav2 目标`

`树结束后回 home`

当前 customer 默认流里没有发生的事：

- 没有 pick action
- 没有 gripper action
- 没有 rack action
- 没有库存扣减

### 8.4 Semantic edit 流

当前 semantic edit 信息流：

`employee login -> bearer token`

`LocationMapView -> GET /api/maps/semantic/current`

`backend -> YAML bundle + map metadata + DB version + inventory enrich`

`user edits geometry`

`LocationMapView -> PUT /api/maps/semantic/current`

`backend -> save YAML -> insert semantic_map_versions snapshot`

### 8.5 SLAM Web visualization 流

当前 SLAM Web 信息流：

`browser 打开 /app/slam-map`

`SlamMapView 加载 iframe /embedded/ros-web-gui/index.html`

`iframe 内部应用直接连接 rosbridge`

`嵌入应用自己渲染 ROS topic`

也就是说当前 live SLAM 页面在实时传输层面绕过了 Express backend。

## 9. 当前技术栈清单

ROS / navigation：

- ROS 2 Humble 风格 launch 与节点
- SICK `sick_scan_xd`
- Cartographer ROS
- Nav2
- robot_localization
- tf2
- 自定义 point-cloud crop filter
- 自定义 serial bridge

任务执行：

- `py_trees`
- Python BT executor
- 自定义 semantic service client
- 自定义 Nav2 action BT 叶子

机械臂：

- MoveIt
- 自定义 `pick_arm` action server
- Interbotix / ViperX 相关实验节点

Backend：

- Node.js
- Express
- PostgreSQL
- `pg`
- 可选 Python `deep-translator`，用于 inventory translation

Frontend：

- Vue 3
- Vue Router
- Vite
- 自定义 Store Map canvas
- 嵌入式 vendored React / Three.js ROS GUI

嵌入式 SLAM viewer：

- vendored `ros_web_gui_app`
- React
- Three.js
- `roslib`
- `rosbridge_server`

## 10. 当前缺口、风险与不一致点

当前最重要的代码真实缺口如下：

1. Restock UI 到 robot execution 仍未打通。
   - UI 写 `restock_id`
   - 默认 executor 只轮询 `order_id`

2. 库存更新语义当前是不一致的。
   - customer 树不改库存
   - restock 树反而减库存

3. Robot status 页面不是 live ROS。
   - 只是 dashboard placeholder 数据

4. Semantic map 主源当前仍是分裂的。
   - YAML 是在线主源
   - DB 是版本历史
   - 直接改 DB 不会驱动当前 UI live bundle

5. Manipulation 只接了一部分。
   - backend action server 已有
   - 默认 BT 路径还没真正 end-to-end 用起来

6. 嵌入式 SLAM 页依赖外部运行时。
   - 需要单独跑 `rosbridge_server`
   - iframe 里的连接不经过 Node backend

7. Nav2 的命令权仍是简单 topic subscription。
   - manual / autonomous 之间还没有真正实现 arbiter

## 11. 当前运行说明

当前推荐入口：

- mapping：
  - `ros2 run robot_navigation nav_assistant mapping-stack`
- localization + Nav2：
  - `ros2 run robot_navigation nav_assistant localization-stack --map-name testmapMain --with-nav2-rviz true`
- backend：
  - `cd order-api-postgre && npm run dev`
- employee UI：
  - `cd order-api-postgre/fleet-manager && npm run dev`
- SLAM 页 live bridge：
  - `ros2 launch rosbridge_server rosbridge_websocket_launch.xml`

当前员工测试登录：

- `000AAA / team21`

## 12. 结论

当前仓库已经不再只是一个“能跑导航”的 ROS 项目，而是出现了一套真实的多表面系统：

- 可用的 mapping / localization / Nav2 栈，
- 在 ROS 和 Web 两侧都存在的 semantic overlay，
- 可编辑的 Store Map 工具，
- 以及一个基于 vendored ROS GUI 的浏览器 SLAM 页面。

但 end-to-end autonomy 还没有完全闭环。

现在导航栈本身比之前真实得多，主要薄弱点已经从“底层算法是否成立”转移到了“流程是否完全接通”上，尤其是：

- customer / restock 的执行语义，
- inventory side effect，
- dashboard 里的 live robot status，
- 以及 BT 到 arm execution 的完整接线。

## 13. 详细 Launch、节点、Topic、Service、Action 清单

### 13.1 Launch 文件清单

| Launch 文件 | 当前用途 | 包含的节点 / include | 关键默认值 |
| --- | --- | --- | --- |
| `launch/slam_mapping_stack.launch.py` | 完整 mapping 栈 | `sick_generic_caller`、2 个 static TF publisher、`base_link_crop_filter`、`cartographer_mapping.launch.py`、`nav2_serial_bridge`、可选 `ekf_node`、可选 collision launch、可选 RViz | crop 默认开启，`cmd_topics=["/cmd_vel","/cmd_vel_nav","/cmd_vel_smoothed"]`，`odom_topic=/odom_raw` |
| `launch/cartographer_mapping.launch.py` | 纯 Cartographer mapping 核心 | `cartographer_node`、`cartographer_occupancy_grid_node` | `configuration_basename=pico_2d_mapping_quality.lua`，`resolution=0.03` |
| `launch/nav2_localization_stack.launch.py` | localization + Nav2 + semantic map | `sick_generic_caller`、2 个 static TF publisher、`nav2_serial_bridge`、可选 `ekf_node`、可选 `base_link_crop_filter`、`cartographer_localization.launch.py`、`map_server`、map lifecycle manager、延迟启动的 `nav2_bringup/navigation_launch.py`、可选 Nav2 RViz、可选 `semantic_map_server` | 默认地图 `testmapMain`，crop 默认关闭，semantic map 默认开启，`cmd_topics=["/cmd_vel"]` |
| `launch/cartographer_localization.launch.py` | Cartographer localization 核心 | `cartographer_node`、可选 `cartographer_occupancy_grid_node` | `configuration_basename=pico_2d_localization.lua`，`load_frozen_state=true`，本地 occupancy grid 默认关闭 |

### 13.2 Runtime executable 清单

#### `robot_navigation` executables

| Executable | 角色 | 发布 | 订阅 | Services / actions | 当前状态 |
| --- | --- | --- | --- | --- | --- |
| `nav2_serial_bridge` | STM32 命令与 telemetry 桥 | 配置的 `odom_topic` 上的 `nav_msgs/Odometry`，可选 TF | 配置的 `cmd_topics`，`/front_alert`，`/back_alert`，`/left_alert`，`/right_alert` | 无 | mapping 与 localization 都在用 |
| `base_link_crop_filter` | 从点云里去掉底盘自击中区域 | 过滤后的 `PointCloud2` | 原始 `PointCloud2` | 无 | mapping 默认启用 |
| `semantic_map_server` | semantic overlay 发布与 semantic target 解析 | `/semantic_map/markers` | 无 | `/semantic_map/resolve_target` | localization 默认启用 |
| `nav_assistant` | launch / save-map / export-map / goal / teleop macro CLI | 在 motion 模式下会临时发 `Twist` | 无持久订阅 | 内部使用 `WriteState`、`NavigateToPose`、`FollowWaypoints` client | 操作员工具，不是常驻 runtime 节点 |
| `teleop_cmd_vel` | 简单键盘 teleop | `Twist` | 无 | 无 | 工具节点 |
| `teleop_cmd_vel_collision` | 带单个碰撞停机输入的键盘 teleop | `Twist` | `right_alert` | 无 | 工具节点，不在主 launch 栈里 |
| `teleop_ros` | 旧版可配置 teleop publisher | `Twist` | 无 | 无 | legacy 工具 |
| `wheel_motor` | 旧版 I2C mecanum 驱动路径 | 无 | 可配置 `cmd_vel`、`obstacle_alert` | 无 | legacy 路径，不是当前 Nav2 主栈的一部分 |

#### `robot_task_manager` executables

| Executable | 角色 | ROS 接口 | 外部接口 | 当前状态 |
| --- | --- | --- | --- | --- |
| `bt_executor` | 默认 customer / employee BT executor | `/order/new` service；BT 内部含 Nav2 action client；BT 内部含 semantic resolve client | 轮询 `GET /api/order/latest`；POST `/api/order/ack`；POST `/api/order/complete`；`ChangeInventory` POST `/api/inventory/decrement` | 当前默认路径 |
| `bt_executor_viperX` | 另一条偏 ViperX 的 executor | 同样提供 `/order/new` service；包含 ViperX 专用 BT nodes | 和默认 executor 一样的 backend polling 模式 | 存在，但不是主业务路径 |

#### `robot_manipulation` executables

| Executable | 角色 | 接口 | 当前状态 |
| --- | --- | --- | --- |
| `arm_controller` | MoveIt-backed arm action server | `PickArm` action、`JointTrajectory` publisher | 已实现且可用 |
| `viperx_arm_server` | MoveIt-backed ViperX arm action server | 默认 `pick_viperx` 的 `PickArm` action | 已实现 |
| `arm_waypoint_server` | waypoint 风格 arm action server | 默认 `pick_arm_waypoint` 的 `PickArm` action | 已实现 |
| `arm_demo_controller` | 简化版 arm demo action server | 默认 `pick_arm_demo` 的 `PickArm` action | 用于 demo / 测试 |
| `rack_controller` | rack lift action server | `move_rack` 上的 `MoveRack` action | 已实现 |
| `arm_motor` | I2C hardware bridge | `JointTrajectory` subscriber | 已实现 |
| `arm_to_gazebo` | 仿真桥 | Gazebo 集成相关 pub / sub | 已实现 |
| `vx300_quick_move.py` | 诊断 / helper 脚本 | publishers + service clients | 工具 |
| `vx300_hardware_diagnostics.py` | 诊断 / helper 脚本 | publishers + service clients + subscriptions | 工具 |

### 13.3 当前主流程里的 ROS topic 清单

#### 导航与定位相关 topics

| Topic | 类型 | Producer | 主要 Consumer | 说明 |
| --- | --- | --- | --- | --- |
| `/cloud_all_fields_fullframe` | `sensor_msgs/PointCloud2` | SICK driver | crop filter、Nav2 costmap | 原始点云 |
| `/cloud_all_fields_fullframe_filtered` | `sensor_msgs/PointCloud2` | crop filter | Cartographer mapping / localization | 当前 Cartographer 输入 |
| `/scan_fullframe` | `sensor_msgs/LaserScan` | SICK driver | 当前不是主 Cartographer 路径 | 仍然可用 |
| `/sick_scansegment_xd/imu` | IMU | SICK driver | EKF、Cartographer | 当前 IMU 路径 |
| `/odom_raw` | `nav_msgs/Odometry` | `nav2_serial_bridge` | EKF | 底盘 raw odom |
| `/odom` | `nav_msgs/Odometry` | EKF | Nav2、Cartographer localization | 过滤后的 odom |
| `/map` | `nav_msgs/OccupancyGrid` | mapping 时来自 Cartographer；localization 时来自 `map_server` | RViz、Nav2、嵌入式 ROS GUI | 来源取决于运行模式 |
| `/cmd_vel` | `geometry_msgs/Twist` | teleop 或 Nav2 路径 | serial bridge | localization 栈默认监听这个 |
| `/cmd_vel_nav` | `geometry_msgs/Twist` | 可选 nav 路径 | mapping 栈默认桥接可监听 | localization 默认不监听 |
| `/cmd_vel_smoothed` | `geometry_msgs/Twist` | 可选 smoother 路径 | mapping 栈默认桥接可监听 | localization 默认不监听 |
| `/semantic_map/markers` | `visualization_msgs/MarkerArray` | semantic map server | RViz | semantic overlay 显示 |

#### 当前接进 bridge 的碰撞 / 安全 topics

| Topic | 类型 | Consumer | 效果 |
| --- | --- | --- | --- |
| `/front_alert` | `std_msgs/Bool` | `nav2_serial_bridge` | 为 true 时禁止前进 |
| `/back_alert` | `std_msgs/Bool` | `nav2_serial_bridge` | 为 true 时禁止后退 |
| `/left_alert` | `std_msgs/Bool` | `nav2_serial_bridge` | 为 true 时禁止向左 |
| `/right_alert` | `std_msgs/Bool` | `nav2_serial_bridge`、`teleop_cmd_vel_collision` | 为 true 时禁止向右 / 让 teleop 停车 |

### 13.4 ROS service 清单

| Service | 类型 | Server | 当前用途 |
| --- | --- | --- | --- |
| `/semantic_map/resolve_target` | `robot_interfaces/srv/ResolveSemanticTarget` | `semantic_map_server` | 把 product / slot / anchor 解析成 nav pose 与 service pose |
| `/order/new` | `robot_interfaces/srv/NewOrder` | `bt_executor` 或 `bt_executor_viperX` | 手工从 ROS 侧注入订单 |
| `/write_state` | `cartographer_ros_msgs/srv/WriteState` | Cartographer | `nav_assistant save-map` 用于保存 pbstream |

### 13.5 ROS action 清单

| Action | 类型 | Server | Client | 当前用途 |
| --- | --- | --- | --- | --- |
| `/navigate_to_pose` 或 `navigate_to_pose` | `nav2_msgs/action/NavigateToPose` | Nav2 | `NavigateToGoalPose`、`nav_assistant goal` | active |
| `/follow_waypoints` | `nav2_msgs/action/FollowWaypoints` | Nav2 | `nav_assistant waypoints` | 工具能力 |
| `pick_arm` | `robot_interfaces/action/PickArm` | 默认由 `arm_controller` 提供 | 默认 BT 路径还没真正用上 | 后端已实现 |
| `pick_viperx` | `robot_interfaces/action/PickArm` | 默认由 `viperx_arm_server` 提供 | ViperX BT nodes | 另一条路径 |
| `move_rack` | `robot_interfaces/action/MoveRack` | `rack_controller` | rack BT node | 后端已实现；默认树路径仍注释中 |

当前实现里的一个重要细节：

- `robot_task_manager/bt_nodes/rack_nodes.py` 仍然在 import `rack_interfaces.action.MoveRack`，但这个仓库真正的接口是 `robot_interfaces/action/MoveRack`。不过这个 BT node 目前也不在默认树导入路径里，所以这个问题当前是“潜伏的”，不是主路径上的 runtime error。

## 14. 完整 Backend / Frontend API Contract

### 14.1 浏览器到 backend 的传输边界

当前前端传输模型：

- Vite dev server 跑在 `5174`
- Vite 把 `/api` proxy 到 `http://localhost:3000`
- 嵌入式 ROS GUI 的静态资源从前端 public 目录下的 `/embedded/ros-web-gui/...` 提供
- SLAM iframe 不通过 backend API 拉实时 ROS 数据，而是直接连 `rosbridge`

### 14.2 Fleet UI 当前实际使用的 endpoints

| Method | Path | Auth | 当前调用方 | 请求结构 | 响应结构 | 说明 |
| --- | --- | --- | --- | --- | --- | --- |
| `POST` | `/api/employee/auth/login` | 否 | `LoginView` | `{ employee_ID, password }` | `{ ok, token, employee }` 或 error | bearer token 来源 |
| `GET` | `/api/employee/inventory/report` | employee | `InventoryReportView` | 无 | `{ summary, category_summary, items }` | 仍然带 legacy `x/y/z` |
| `GET` | `/api/maps/semantic/current` | employee | `LocationMapView` | 无 | 含 `map`、`anchors`、`racks`、`slots`、`summary`、`version`、`generated_at` 的 semantic bundle | 基于 YAML 读出 |
| `PUT` | `/api/maps/semantic/current` | employee | `LocationMapView` | `{ bundle, change_summary }` | `{ ok, bundle, saved_at }` | 同时写 YAML 和 DB version |
| `GET` | `/api/employee/robot/status` | employee | `RobotStatusView` | 无 | `{ robots: [...] }` | 当前是 placeholder 数据 |
| `GET` | `/api/employee/inventory/options` | employee | `RestockView` | 无 | `{ items: [...] }` | restock 下拉产品列表 |
| `POST` | `/api/employee/restock/submit` | employee | `RestockView` | `{ items: [{ product_id, qty }] }` | `{ status, restock_ID }` | 只写 `restock_id` |
| `GET` | `/api/employee/accounts` | employee | `EmployeeAccountsView` | 无 | `{ items: [...] }` | 员工列表 |
| `POST` | `/api/employee/accounts/create` | employee | `EmployeeAccountsView` | `{ employee_ID, first_name, last_name, password }` | `{ ok, employee_ID, first_name, last_name }` | 明文密码入库 |

### 14.3 机器人执行链实际使用的 backend endpoints

| Method | Path | Auth | 当前调用方 | 请求结构 | 响应结构 | 说明 |
| --- | --- | --- | --- | --- | --- | --- |
| `GET` | `/api/order/latest` | 否 | `bt_executor`、`bt_executor_viperX` | 无 | `204` 或 `{ order_id, role, requester_id, items }` | 只读 `order_id`，不读 `restock_id` |
| `POST` | `/api/order/ack` | 否 | executors | `{ order_id }` | `{ ok }` | 把 `order_id.status` 置为 `IN_PROGRESS` |
| `POST` | `/api/order/complete` | 否 | executors | `{ order_id, result }` | `{ ok }` | 更新 `order_id`，不更新 `restock_id` |
| `POST` | `/api/inventory/decrement` | 否 | `ChangeInventory` BT node | `{ product_id, qty }` | `{ ok }` | 当前 restock 树也在错误地用这条 |

### 14.4 Public / customer endpoints

| Method | Path | Auth | 请求结构 | 响应结构 | 说明 |
| --- | --- | --- | --- | --- | --- |
| `POST` | `/api/auth/login` | 否 | `{ member_ID }` | customer identity block | member 登录，不要密码 |
| `POST` | `/api/account/create_customer` | 否 | `{ first_name, last_name }` | `{ ok, member_ID, first_name, last_name }` | 自动生成 member ID |
| `GET` | `/api/inventory/list` | 否 | query `lang` 可选 | `{ items }` | 可通过 `deep-translator` 翻译 |
| `POST` | `/api/order/customer` | 否 | `{ member_ID or id, guest, items }` | `{ status, order_id }` | 当前 customer 下单主路径 |
| `GET` | `/api/order/status/:id` | 否 | path ID | `{ order_id, status, result, timestamp }` | `/api` 版本 |

### 14.5 Semantic 与地图资产接口

| Method | Path | Auth | 请求 | 响应 | 说明 |
| --- | --- | --- | --- | --- | --- |
| `GET` | `/api/maps/base/:mapName.pgm` | 否 | path map name | PGM 文件字节流 | Store Map 底图 |
| `GET` | `/api/maps/semantic/current` | employee | 无 | semantic bundle | Store Map 主数据源 |
| `PUT` | `/api/maps/semantic/current` | employee | semantic bundle | saved bundle + version | 双向保存路径 |

### 14.6 仍然保留的 legacy compatibility endpoints

这些接口在 `server.js` 里还存在，但它们不是当前 fleet-manager 的主 contract：

| Method | Path | 当前角色 |
| --- | --- | --- |
| `POST` | `/order/customer/new` | 旧 customer 下单路径 |
| `POST` | `/order/employee/new` | 旧 employee restock 路径 |
| `GET` | `/inventory/list/all` | 原始库存列表 |
| `GET` | `/inventory/list/category` | 分类过滤库存列表 |
| `POST` | `/inventory/add` | 新增库存行 |
| `POST` | `/inventory/update` | 更新库存行 |
| `POST` | `/inventory/delete` | 删除库存行 |
| `GET` | `/order/status/:id` | 旧 order-status 路径 |
| `POST` | `/order/complete` | 旧 completion 路径 |

## 15. 文字版时序流

### 15.1 Employee auth 流

1. 浏览器打开 `/login`
2. 用户输入 `employee_ID` 和 `password`
3. `LoginView` 调 `POST /api/employee/auth/login`
4. Backend 在 `employee` 表里校验账号密码
5. Backend 生成一个 12 小时 TTL 的内存 session token
6. 前端把 `fleet_token`、`fleet_employee_id`、`fleet_first_name`、`fleet_last_name` 写进 `localStorage`
7. Vue Router guard 允许用户进入 `/app/...`

失败边界：

- backend 重启后，内存里的 employee session 会消失
- 浏览器 `localStorage` 里还保留旧 token，直到下一次请求收到 `401`

### 15.2 Store Map 加载流

1. 用户进入 `/app/location-map`
2. 浏览器带 bearer token 调 `GET /api/maps/semantic/current`
3. Backend 读取：
   - `workspace/src/robot_navigation/config/semantic_map_testmapMain.yaml`
   - `Maps/testmapMain.yaml`
   - `Maps/testmapMain.pgm`
   - `semantic_map_versions` 最新版本行
   - 相关 `inventory` 行
4. Backend 返回一个 enriched bundle
5. `LocationMapView` 把它 clone 成：
   - `savedBundle`
   - 可编辑的 `bundle`
6. `SemanticMapCanvas` 再通过 `/api/maps/base/testmapMain.pgm` 拉取底图
7. Canvas 用以下公式把 map 坐标转成像素：
   - `px = (x - origin_x) / resolution`
   - `py = height_px - (y - origin_y) / resolution`
8. Canvas 再把内容或整图 auto-fit 到 viewport

### 15.3 Store Map 保存流

1. 用户拖拽或手工数值编辑 anchor / rack / slot
2. 页面本地状态把 bundle 标记为 dirty
3. 用户点击 `Save`
4. 前端调 `PUT /api/maps/semantic/current`，发 `{ bundle, change_summary }`
5. Backend 先把当前 YAML 文本读出来，作为 rollback backup
6. Backend 把 bundle 序列化回 YAML 并写盘
7. Backend 往 `semantic_map_versions` 里插一条新版本
8. 如果 DB insert 失败，backend 会把旧 YAML 文本写回去
9. Backend 返回标准化后的 saved bundle 和 version
10. 前端用返回值替换本地 draft，并清掉 dirty 状态

### 15.4 SLAM 页面加载流

1. 用户打开 `/app/slam-map`
2. `SlamMapView` 加载 iframe 源 `/embedded/ros-web-gui/index.html`
3. 这个 iframe 应用来自前端静态资源，不是 backend API
4. 嵌入式 ROS GUI 自己初始化连接页
5. 用户在里面连接 `ws://<host>:9090`
6. `rosbridge_server` 成为 map、TF、scan、overlay 等 live ROS 数据的传输层

重要边界：

- 主 Vue app 不参与 SLAM 页 live ROS 数据的中转

### 15.5 Restock submit 流

1. 员工打开 `/app/restock`
2. 前端先调用 `/api/employee/inventory/options` 拉产品列表
3. 员工把选中的 product id 和 qty 加入本地 cart
4. 前端调 `POST /api/employee/restock/submit`
5. Backend 校验 product id 与 qty
6. Backend 插入一条新的 `restock_id`
7. Backend 同步更新 `employee.restock_ID`
8. 前端显示生成的 `restock_ID`

当前更大流程里的断点：

- 默认 `bt_executor` 不轮询 `restock_id`
- 所以这个提交动作目前只走到数据库持久化，不会自动进入机器人执行

## 16. 参数解释与技术说明

### 16.1 Cartographer mapping / localization 参数解释

当前 mapping 文件：

- `config/pico_2d_mapping_quality.lua`

当前 localization 文件：

- `config/pico_2d_localization.lua`

关键参数组及其当前含义：

| 参数 / 参数组 | 当前取值方向 | 当前实际含义 |
| --- | --- | --- |
| `map_frame = "map"` | 固定 | 全局地图坐标系 |
| `tracking_frame = "imu_link"` | 固定 | Cartographer 跟踪的是 IMU frame，不是 `base_link` |
| `published_frame = "base_link"` | 固定 | 下游仍以 `base_link` 作为机器人平面位姿输出 |
| `odom_frame = "odom"` | 固定 | 和 EKF 输出链一致 |
| `provide_odom_frame = true` | 开启 | Cartographer 可以维护 map/odom 关系 |
| `publish_frame_projected_to_2d = true` | 开启 | 给平面导航消费者输出 2D projected 机器人位姿 |
| `use_odometry = true` | 开启 | Cartographer 使用 odom 作为运动先验 |
| `use_imu_data = true` | 开启 | IMU 用于提升姿态稳定性 |
| `num_point_clouds = 1` | 开启 | PointCloud2 是当前主输入路径 |
| `num_laser_scans = 0` | 关闭 | LaserScan 不是当前主 mapping/localization 输入 |
| `submaps.num_range_data = 60` | 中等偏质量 | 每个 submap 累积 60 组 range data 再向前滚动 |
| `grid_options_2d.resolution = 0.03` | 固定 | 与导出地图分辨率对齐 |
| `min_range = 0.15`，`max_range = 10.0` | 较宽 | 接受较近回波与完整 aisle 范围回波 |
| `missing_data_ray_length = 10.0` | 较宽 | unknown-space ray 长度与最大有效距离一致 |
| `use_online_correlative_scan_matching = true` | 开启 | 提高局部 scan matching 鲁棒性，但算力更高 |
| `linear_search_window = 0.2` | 中等 | 平移方向搜索窗口 |
| `translation_delta_cost_weight = 0.1` | 惩罚较低 | 允许 translational search 较自由 |
| `rotation_delta_cost_weight = 0.1` | 惩罚较低 | rotation search 也较自由 |
| `motion_filter.*`（mapping） | 阈值较严 | 避免插入过多重复观测 |
| `pure_localization_trimmer.max_submaps_to_keep = 3`（localization） | 开启 | localization 模式下控制内存中的 submap 数量 |
| `constraint_builder.min_score = 0.62` | 中等偏严格 | 拒绝较弱的匹配约束 |
| `odometry_translation_weight = 1e3`，`odometry_rotation_weight = 1e3` | 较高 | 优化时对 odom 约束信任较强 |

当前实际解释：

- 整套配置偏向“odom + IMU + cloud 一起工作”的稳定 store / warehouse localization
- 它不是一个轻量的 scan-only 配置

### 16.2 EKF 参数解释

当前 EKF 文件：

- `config/ekf_odom_base_imu.yaml`

重要参数组：

| 参数 / 参数组 | 当前行为 | 实际效果 |
| --- | --- | --- |
| `frequency = 50.0` | 较高 | EKF 以 50 Hz 输出 |
| `sensor_timeout = 0.3` | 中等 | 输入 stale 后较快剔除 |
| `two_d_mode = true` | 开启 | 把机器人状态限制在平面 |
| `publish_tf = false` | 关闭 | EKF 不成为另一套 TF authority |
| `world_frame = odom` | 固定 | 过滤后的状态保持 odom 参考系 |
| `odom0 = /odom_raw` | active | bridge raw odom 是运动输入 |
| `odom0_config` | 偏 twist 选择 | 更信任平面速度和角速度，而不是 raw absolute pose |
| `imu0 = /sick_scansegment_xd/imu` | active | 融合 IMU yaw 与 yaw rate |
| `imu0_remove_gravitational_acceleration = false` | 保持默认 | 不做额外重力加速度移除预处理 |
| `imu0_config` | 只用 yaw + yaw rate | IMU 主要负责 heading 稳定 |
| `process_noise_covariance` | 已调矩阵 | 决定平滑与响应之间的取舍 |

当前实际解释：

- EKF 当前本质上是对 bridge odom 与 IMU heading 做一个平面滤波
- 不是一套完整的 3D inertial fusion 栈

### 16.3 Nav2 参数解释

当前 Nav2 文件：

- `config/nav2_params_smac_mppi_omni.yaml`

主要 section：

| Section | 当前角色 | 说明 |
| --- | --- | --- |
| `amcl` | 文件里有，但运行栈里没启 | 当前 localization 栈没有 launch AMCL，这一段实际上是 dormant 配置 |
| `bt_navigator` | Nav2 的行为树导航器 | 使用 Nav2 默认 BT XML 和 plugin 集合 |
| `controller_server` | 局部控制 | 当前插件是 `MPPIController` |
| `planner_server` | 全局路径规划 | 当前插件是 `SmacPlanner2D` |
| `local_costmap` | `odom` 坐标系下的短程 obstacle space | `VoxelLayer + InflationLayer` |
| `global_costmap` | `map` 坐标系下的规划 costmap | static map + obstacle + inflation |
| `behavior_server` | recovery 与简单 behavior action | spin、backup、drive-on-heading、assisted teleop、wait |
| `waypoint_follower` | waypoint 执行 | 配置了 wait-at-waypoint plugin |
| `velocity_smoother` | 速度平滑 | 配置已在，但 localization 栈的 bridge 默认仍只监听 `/cmd_vel` |

关键 planner / controller 参数：

| 参数 / 参数组 | 当前取值方向 | 实际效果 |
| --- | --- | --- |
| `FollowPath.plugin = nav2_mppi_controller::MPPIController` | active | 采用优化式局部控制 |
| `motion_model = "Omni"` | active | 允许横移 |
| `vx_max = 0.26`，`vy_max = 0.20`，`wz_max = 1.0` | 偏保守 | 限制底盘最大速度 |
| `batch_size = 1000`，`time_steps = 56` | 较重 | MPPI 会采样较多轨迹 |
| `VelocityDeadbandCritic.deadband_velocities = [0.08, 0.07, 0.12]` | active | 避免控制输出落在底盘 deadband 内 |
| `GridBased.plugin = nav2_smac_planner/SmacPlanner2D` | active | 基于 occupancy costmap 做 2D 图搜索规划 |
| `allow_unknown = true` | active | planner 可穿过 unknown 区域 |
| `cost_travel_multiplier = 2.0` | 中等 | 障碍物附近 cost 会明显影响路径 |

关键 costmap 参数：

| 参数 / 参数组 | 当前设置 | 实际含义 |
| --- | --- | --- |
| local costmap `global_frame = odom` | rolling local frame | 反应式控制在 odom 参考系下工作 |
| global costmap `global_frame = map` | map-fixed | 长程规划使用全局地图坐标 |
| `robot_radius = 0.40` | 共用 | 当前碰撞包络假设 |
| obstacle topic `/cloud_all_fields_fullframe` | local/global 都在用 | Nav2 obstacle 仍直接看 raw cloud |
| inflation radius `0.55` | 中等 | 让规划路径离障碍物更远一些 |

### 16.4 前端地图坐标转换

当前 Store Map 页面使用以下 ROS map 坐标到 raster 像素的转换：

- `px = (x - origin_x) / resolution`
- `py = map_height_px - (y - origin_y) / resolution`

逆变换：

- `x = origin_x + px * resolution`
- `y = origin_y + (map_height_px - py) * resolution`

这也是为什么：

- map YAML 里的 `origin` 不等于“机器人 home pose”
- 即便 raster origin 不是 `(0,0,0)`，semantic anchor 也完全可以合法地使用 `(0,0,0)`

## 17. 当前未完成项与风险矩阵

| Area | 当前代码现实 | 风险 | 严重度 | 建议下一步 |
| --- | --- | --- | --- | --- |
| Restock execution intake | employee UI 写 `restock_id`，默认 executor 只轮询 `order_id` | restock request 不会自动进入机器人执行 | High | 增加 `/api/restock/latest|ack|complete` 或统一 polling contract |
| Inventory side effects | customer 树不改库存；restock 树反而减库存 | 业务语义与库存状态会持续偏离 | High | 拆分 increment / decrement endpoint，并按 workflow 类型调用 |
| Robot status page | backend 里是占位坐标和电量 | UI 容易被误认为是真实 fleet telemetry | Medium | 接 ROS 真数据，或明确标注为 simulated |
| Semantic source-of-truth | YAML 是 live source，DB 只是 version history | 直接改 DB 不会影响当前 active semantic map | Medium | 选定 DB-primary 或保持 YAML-primary 但提供正式 sync 工具 |
| SLAM page runtime dependency | 嵌入式 app 依赖额外 `rosbridge_server` | 操作员若不知道额外步骤，页面会像“坏掉” | Medium | 加 diagnostics banner 或可选 launch helper |
| Store Map help copy | `i18n.js` 仍写着 Store Map / SLAM 是 placeholders | UI 文案和真实功能不一致 | Low | 更新 help 文案和翻译 |
| Rack BT node | `rack_nodes.py` import 的是 `rack_interfaces` 而不是 `robot_interfaces`，且当前不在默认导入路径 | 后面若启用 rack BT 可能直接 import/runtime 失败 | Medium | 修正 import 并在启用前补测试 |
| Default arm BT path | generic arm nodes 仍是 TODO / 注释状态 | 机器人能导航到位，但 manipulation 流不会闭环 | High | 把 `pick_arm` 正式接进默认 customer / restock 树 |
| Costmap obstacle source | Nav2 costmap 用 raw cloud，不是 filtered cloud | 某些姿态下自击中点仍可能影响规划 | Medium | 明确决定 Nav2 是否也切到 filtered cloud |
| Auth model | 明文密码 + 内存 session | 安全性弱，backend 重启即掉登录态 | Medium | 密码哈希化，并改为 JWT 或持久 session |

## 18. 功能到文件的直接映射

| 功能 | 主要文件 |
| --- | --- |
| Mapping bringup | `launch/slam_mapping_stack.launch.py`、`launch/cartographer_mapping.launch.py`、`config/pico_2d_mapping_quality.lua` |
| Localization + Nav2 bringup | `launch/nav2_localization_stack.launch.py`、`launch/cartographer_localization.launch.py`、`config/pico_2d_localization.lua`、`config/nav2_params_smac_mppi_omni.yaml` |
| Odom bridge 与 telemetry | `robot_navigation/nav2_serial_bridge.py`、`config/ekf_odom_base_imu.yaml` |
| Semantic map runtime | `robot_navigation/semantic_map_server.py`、`config/semantic_map_testmapMain.yaml`、`robot_interfaces/srv/ResolveSemanticTarget.srv` |
| 默认 BT 执行链 | `robot_task_manager/bt_executor.py`、`trees/customer.py`、`trees/restock.py`、`bt_nodes/semantic_nodes.py`、`bt_nodes/navigation_nodes.py`、`bt_nodes/inventory_nodes.py` |
| Store Map UI | `fleet-manager/src/views/LocationMapView.vue`、`fleet-manager/src/components/SemanticMapCanvas.vue`、`order-api-postgre/semantic_map.js`、`order-api-postgre/server.js` |
| SLAM UI 外层壳 | `fleet-manager/src/views/SlamMapView.vue`、`fleet-manager/public/embedded/ros-web-gui`、`third_party/ros_web_gui_app` |
| 员工认证与 dashboard APIs | `order-api-postgre/server.js`、`fleet-manager/src/api.js`、`fleet-manager/src/router/index.js`、`fleet-manager/src/layouts/FleetLayout.vue` |

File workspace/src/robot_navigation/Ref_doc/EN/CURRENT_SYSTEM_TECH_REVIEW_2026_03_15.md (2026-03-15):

# Current System Tech Review

Date: 2026-03-15

Scope:
- This review describes the current code as it exists on 2026-03-15.
- It is intentionally code-faithful, not design-intent-faithful.
- It covers the navigation stack, semantic map layer, task execution path, and the current web/backend integration around Store Map and SLAM viewing.

This document should be read as a current-state companion to the older navigation reviews in `Ref_doc/CN` and `Ref_doc/EN`. Where older reviews describe historical states, this document describes what the code is doing now.

## 0. Executive Summary

The current system is now a multi-layer stack made of:

- ROS 2 navigation and localization built around SICK PicoScan, Cartographer, EKF, and Nav2.
- A semantic overlay layer implemented in ROS and mirrored into the employee web UI.
- A PostgreSQL + Node.js backend serving inventory, employee auth, order APIs, semantic map APIs, and semantic-map version history.
- A Vue-based employee dashboard with:
  - a custom editable Store Map page, and
  - a SLAM page that embeds a vendored ROS web GUI app through an iframe.

The most important current architectural facts are:

- Mapping and localization are both PointCloud2-based Cartographer pipelines.
- Localization uses Cartographer localization plus a static map server, not AMCL.
- Nav2 uses `SmacPlanner2D + MPPIController` with omni motion enabled.
- The semantic map is currently read from YAML as the live source of truth.
- Database semantic versions are history snapshots, not the primary read source.
- The Store Map page can edit the semantic map and save back to both YAML and PostgreSQL version history.
- The SLAM page is not a custom canvas anymore; it is a wrapper around a vendored `ros_web_gui_app` fork that connects to `rosbridge` directly inside the iframe.

The system is functional, but several workflow mismatches remain:

- The default BT executor only polls customer orders, not employee restock tasks.
- The customer BT tree currently navigates but does not update inventory.
- The restock BT tree currently calls the inventory decrement endpoint, which is backward for restocking.
- The robot status page still uses placeholder backend data, not live ROS telemetry.
- The embedded SLAM page needs a separate `rosbridge_server`; it is not routed through the Node backend.

## 1. Codebase Boundary and Current Relevant Packages

### 1.1 ROS packages

Relevant ROS packages in `workspace/src`:

- `robot_navigation`
  - launch composition
  - Cartographer configs
  - Nav2 params
  - serial bridge
  - base-link crop filter
  - semantic map server
  - helper CLI (`nav_assistant`)
- `robot_task_manager`
  - blackboard
  - BT executor
  - BT nodes
  - customer/restock trees
  - alternate ViperX BT path
- `robot_interfaces`
  - `Order`, `OrderItem`
  - `NewOrder.srv`
  - `ResolveSemanticTarget.srv`
  - `MoveRack.action`
  - `PickArm.action`
- `robot_manipulation`
  - MoveIt launch for VX300
  - `pick_arm` action server

### 1.2 Web/backend packages

Relevant web/backend folders:

- `order-api-postgre`
  - Express backend
  - PostgreSQL access
  - semantic map file parsing and save logic
- `order-api-postgre/fleet-manager`
  - employee-facing Vue dashboard
  - Store Map page
  - SLAM page shell
- `third_party/ros_web_gui_app`
  - vendored source from `StarLionJiang/ros_web_gui_app`
  - translated to English for the embedded SLAM view

### 1.3 Map assets and semantic assets

Current map assets:

- `Maps/testmapMain.pbstream`
- `Maps/testmapMain.yaml`
- `Maps/testmapMain.pgm`

Current semantic overlay asset:

- `workspace/src/robot_navigation/config/semantic_map_testmapMain.yaml`

Important current map facts:

- map name: `testmapMain`
- map resolution: `0.03 m/pixel`
- map origin in `map` frame: `[-2.797711, -10.398200, 0.0]`
- semantic map id: `testmapMain`
- semantic home anchor is configured as `(0.0, 0.0, 0.0)`

## 2. Current Navigation Stack

### 2.1 Mapping stack

Current mapping launch entry:

- `ros2 launch robot_navigation slam_mapping_stack.launch.py`
- or `ros2 run robot_navigation nav_assistant mapping-stack`

Current mapping stack composition:

- SICK PicoScan driver via `sick_generic_caller`
- static TF `base_link -> lidar_link`
- static TF `lidar_link -> imu_link`
- `base_link_crop_filter`
- Cartographer mapping
- serial bridge
- optional EKF
- optional ultrasonic collision launch
- optional RViz

Current mapping sensor path:

- LiDAR raw point cloud: `/cloud_all_fields_fullframe`
- cropped point cloud for Cartographer: `/cloud_all_fields_fullframe_filtered`
- IMU topic: `/sick_scansegment_xd/imu`

Current mapping behavior:

- Cartographer mapping consumes the cropped point cloud.
- Cartographer publishes occupancy grid through `cartographer_occupancy_grid_node`.
- The crop filter is enabled by default in mapping.
- The crop filter exists to remove self-hits from the robot body before Cartographer sees the cloud.

Current Cartographer mapping configuration facts:

- `tracking_frame = "imu_link"`
- `published_frame = "base_link"`
- `odom_frame = "odom"`
- `use_odometry = true`
- `use_imu_data = true`
- `num_point_clouds = 1`
- `num_laser_scans = 0`
- `publish_frame_projected_to_2d = true`

This means the current mapping path is not a LaserScan-first pipeline. It is a PointCloud2 + IMU + odom pipeline.

### 2.2 Localization + Nav2 stack

Current localization entry:

- `ros2 launch robot_navigation nav2_localization_stack.launch.py`
- or `ros2 run robot_navigation nav_assistant localization-stack --map-name testmapMain`

Current localization stack composition:

- SICK PicoScan driver
- static TFs
- serial bridge
- optional EKF
- optional crop filter, disabled by default
- Cartographer localization with `pbstream`
- `nav2_map_server` serving `testmapMain.yaml`
- lifecycle manager for map server
- Nav2 bringup delayed by 2 seconds
- optional Nav2 RViz
- semantic map server enabled by default

Important localization behavior:

- Cartographer localization loads the saved `pbstream` state.
- `publish_occupancy_grid` is disabled in localization mode.
- `/map` in localization mode comes from `nav2_map_server`, not from Cartographer.
- Cartographer still provides localization and TF behavior; the static occupancy grid comes from the exported map YAML/PGM.

This is the key distinction:

- mapping mode: Cartographer generates the map
- localization mode: Cartographer localizes against `pbstream`, while `map_server` serves the exported static map

### 2.3 EKF path

Current EKF config:

- input odom: `/odom_raw`
- input IMU: `/sick_scansegment_xd/imu`
- output: `/odom`
- `publish_tf: false`
- `world_frame: odom`
- `two_d_mode: true`

Current effective flow:

`STM32 telemetry -> nav2_serial_bridge -> /odom_raw`

`/odom_raw + /sick_scansegment_xd/imu -> robot_localization EKF -> /odom`

### 2.4 Nav2 stack

Current Nav2 parameter file:

- `workspace/src/robot_navigation/config/nav2_params_smac_mppi_omni.yaml`

Current active planner/controller stack:

- planner: `nav2_smac_planner/SmacPlanner2D`
- controller: `nav2_mppi_controller::MPPIController`
- motion model: `Omni`

Current costmap behavior:

- local costmap:
  - rolling window in `odom`
  - `VoxelLayer + InflationLayer`
  - point cloud source: `/cloud_all_fields_fullframe`
- global costmap:
  - static map in `map`
  - `StaticLayer + ObstacleLayer + InflationLayer`
  - obstacle source: `/cloud_all_fields_fullframe`

Important current behavior:

- Cartographer receives the cropped cloud in mapping and optionally in localization.
- Nav2 costmaps still use the raw point cloud topic, not the cropped topic.
- So the crop filter currently protects Cartographer input, not Nav2 obstacle layers.

### 2.5 Serial bridge and command transport

Current serial bridge:

- node: `robot_navigation/nav2_serial_bridge.py`
- purpose:
  - forward `/cmd_vel`-style commands to STM32 over serial
  - decode telemetry into odometry
  - optionally publish fallback odom if telemetry stalls

Current default bridged topics:

- mapping stack: `["/cmd_vel", "/cmd_vel_nav", "/cmd_vel_smoothed"]`
- localization stack: `["/cmd_vel"]`

Current authority model:

- there is no command arbiter yet
- whichever subscribed command arrives last can win
- older planning documents mention a future arbiter, but it is not implemented in the current code path

## 3. Current Semantic Map Stack
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

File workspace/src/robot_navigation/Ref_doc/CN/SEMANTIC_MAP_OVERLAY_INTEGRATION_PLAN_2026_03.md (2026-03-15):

# Semantic Map Overlay Integration Plan (2026-03-15)

## 0. 文档目标

本文档用于把当前 Grocery Robot 的 `testmapMain` 静态地图，扩展成一套可落地的语义地图系统，覆盖以下四层：

1. UI 编辑与运行态显示
2. Node.js 后端与 PostgreSQL 数据模型
3. ROS2 导航 / 任务树 / 动作执行接入
4. 地图版本、坐标变换、兼容迁移策略

本文基于两份代码基线整理：

- 当前主仓库：`F:\EC463\EC463_Team_21_Grocery_Robot`
- 旁边带 UI / PostgreSQL / fleet manager 的分支仓库：`F:\EC463\WithUI branch\EC463_Team_21_Grocery_Robot`

本文是正式实施计划，不是只给讨论用的草稿。

---

## 1. 当前代码事实

### 1.1 地图资产事实

当前主仓库已存在可直接用于 overlay 的静态地图资产：

- `Maps/testmapMain.pbstream`
- `Maps/testmapMain.yaml`
- `Maps/testmapMain.pgm`

`testmapMain.yaml` 当前关键参数：

- `resolution = 0.03 m/pixel`
- `origin = [-2.797711, -10.398200, 0.0]`

`testmapMain.pgm` 当前像素尺寸：

- `width = 428 px`
- `height = 840 px`
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

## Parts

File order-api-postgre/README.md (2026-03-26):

# How to run this server

## Local Run on Linux

This setup runs `order-api-postgre` directly on Linux with a native PostgreSQL service + Gemini API. Docker is not required.

### Prerequisites

- Ubuntu/Debian-style Linux shell commands are used below
- Node.js 20+
- npm 10+
- PostgreSQL 14+
- Python 3 if you want inventory translation to work
- `psql` available in your shell
- Gemini API

### 1. Install PostgreSQL + Gemini

```bash
sudo apt update
sudo apt install -y postgresql postgresql-contrib
sudo systemctl enable --now postgresql
```

```bash
# Obtain a Google AI API key from https://makersuite.google.com/app/apikey
# Create the config directory and gemini.json file
mkdir -p config
echo '{
  "apiKey": "...",
  "model": "gemini-2.0-flash"
}' > config/gemini.json
```

### 2. Create the database and role

The backend defaults to these connection values:

- host: `localhost`
- port: `5432`
- db: `grocery_inventory`
- user: `grocerybot`
- password: `team21`

Create them with:

```bash
sudo -u postgres psql
```

Inside `psql`:

```sql
CREATE ROLE grocerybot WITH LOGIN PASSWORD 'team21';
CREATE DATABASE grocery_inventory OWNER grocerybot;
\q
```

If the role or database already exists, skip the matching command.

### 3. Load schema and seed data

From the repo root:

```bash
cd order-api-postgre
PGPASSWORD=team21 psql -h localhost -U grocerybot -d grocery_inventory -f db/init/001_schema.sql
PGPASSWORD=team21 psql -h localhost -U grocerybot -d grocery_inventory -f db/init/002_seed.sql
```

Seed employee login:

- `000AAA` / `team21`

### 4. Start the backend

From `order-api-postgre`:

```bash
npm install
python3 -m pip install deep-translator
export PGHOST=localhost
export PGPORT=5432
export PGDATABASE=grocery_inventory
export PGUSER=grocerybot
export PGPASSWORD=team21
npm run dev
```

Backend URL:

- `http://localhost:3000`

Notes:

- You can omit the `export` lines if you want to use the backend defaults.
- `PORT` can also be overridden, for example `export PORT=3001`.
- `node server.js` also works if you do not want file-watch mode.
- You do not need `npm init -y` here because `package.json` is already committed.

### 5. Start the fleet UI

Open a second terminal:

```bash
cd order-api-postgre/fleet-manager
npm install
npm run dev -- --host 0.0.0.0
```

Frontend URL:

- `http://localhost:5174`

Notes:

- You do not need `npm init -y` in `fleet-manager` either; the Vite/Vue project files are already committed.

### 6. Optional ROS2 BT executor

If you want the full robot stack to consume orders/restock tasks after the API and UI are up,
open a third terminal and run the ROS2 task manager node.

Example:

```bash
source /opt/ros/$ROS_DISTRO/setup.bash
source workspace/install/setup.bash
ros2 run robot_task_manager bt_executor
```

This is only meaningful if your ROS2 workspace has already been built and the required Nav2 /
manipulation nodes are running.

### 7. Optional database checks

Connect to PostgreSQL:

```bash
PGPASSWORD=team21 psql -h localhost -U grocerybot -d grocery_inventory
```

Useful checks:

```sql
\dt
SELECT * FROM employee;
SELECT * FROM inventory;
SELECT * FROM semantic_map_versions ORDER BY version_seq DESC;
```

### Embedded ROS Web GUI Attribution

`SlamMapView` in the fleet UI uses an adapted copy of `ros_web_gui_app`.

- Original upstream repository: https://github.com/chengyangkj/ros_web_gui_app
- Fork used by this repository: https://github.com/StarLionJiang/ros_web_gui_app
- Local adaptation in this repository: English localization and embedded integration for the Grocery Robot web dashboard
- Vendored source location: `third_party/ros_web_gui_app`

License summary for the embedded ROS Web GUI component:

- License: `CC BY-NC-SA 4.0`
- Allowed: study, research, and personal use
- Allowed: modification and redistribution, provided the original project attribution is preserved
- Not allowed: commercial use
- Required: derivative works must remain under the same license and include a link to the original project

For full license terms, see `third_party/ros_web_gui_app/LICENSE`.

Acknowledgements:

- Special thanks to the Lichtblick project for the open-source visualization and message-processing ecosystem, especially `@lichtblick/rosmsg` and `@lichtblick/rosmsg-serialization`.
- Thanks to all contributors and users of the original project and this adapted version.

Original upstream markdown preserved in the vendor tree:

- `third_party/ros_web_gui_app/README.md`

### Notes

- The map pages require employee login because the API uses bearer auth.
- The semantic map is read from `workspace/src/robot_navigation/config/semantic_map_testmapMain.yaml`.
- The base raster is read from `Maps/testmapMain.pgm`.
- `docker-compose.yml` is optional local tooling only; this README does not depend on it.
- `firebase-admin` is not used by the current `order-api-postgre` code, so it is not required in setup.

## Local Run on Windows

### Prerequisites

- Node.js 20+
- Docker Desktop running

### 1. Start PostgreSQL

```powershell
cd F:\EC463\EC463_Team_21_Grocery_Robot\order-api-postgre
docker compose up -d
```

Database credentials:

- host: `localhost`
- port: `5432`
- db: `grocery_inventory`
- user: `grocerybot`
- password: `team21`

Seed employee login:

- `000AAA` / `team21`

### 2. Start backend

```powershell
cd F:\EC463\EC463_Team_21_Grocery_Robot\order-api-postgre
npm install
npm run dev
```

Backend URL:

- `http://localhost:3000`

### 3. Start fleet UI

```powershell
cd F:\EC463\EC463_Team_21_Grocery_Robot\order-api-postgre\fleet-manager
npm install
npm run dev
```

Frontend URL:

- `http://localhost:5174`

### Notes

- The map pages require employee login because the API uses bearer auth.
- The semantic map is read from `workspace/src/robot_navigation/config/semantic_map_testmapMain.yaml`.
- The base raster is read from `Maps/testmapMain.pgm`.

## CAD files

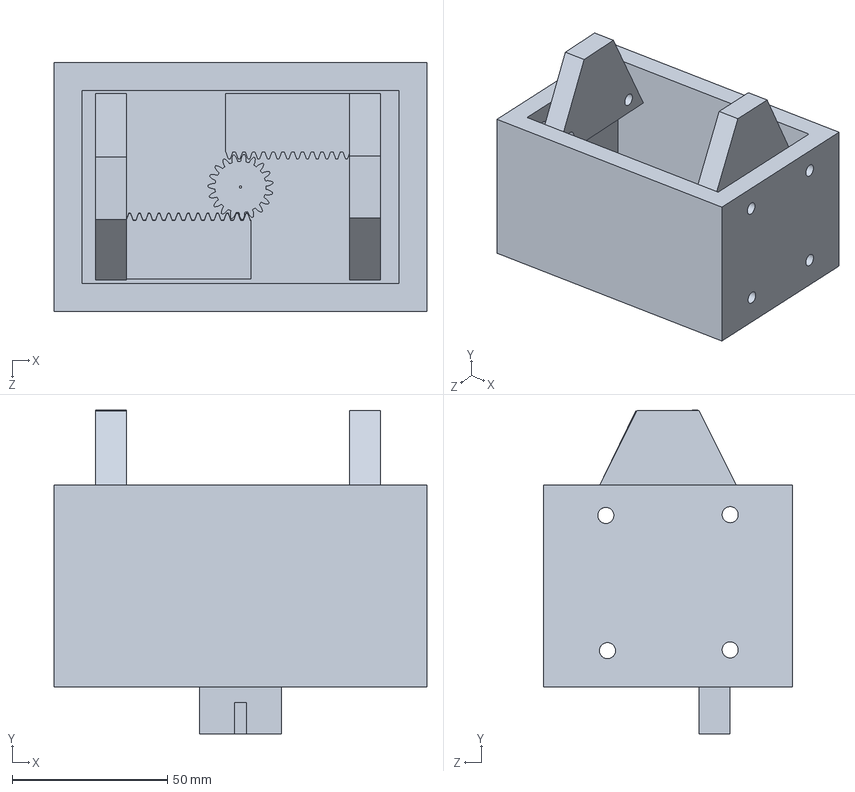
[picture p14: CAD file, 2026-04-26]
hardware/robotic arm/full_part.SLDPRT
120.0 x 104.1 x 80.0 mm

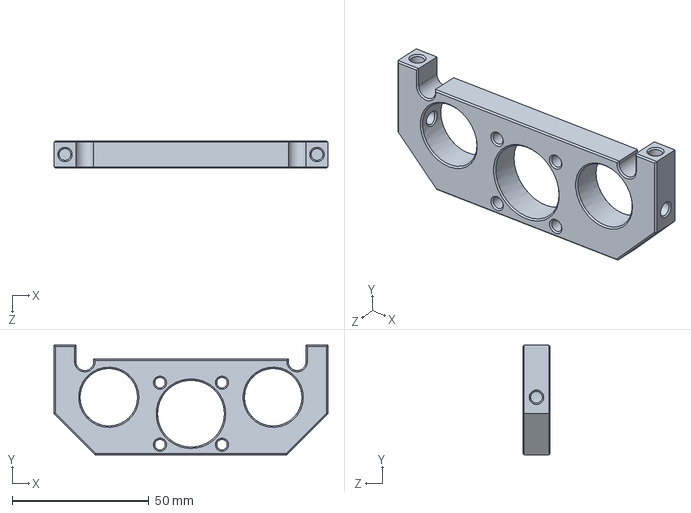
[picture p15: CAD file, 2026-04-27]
hardware/Linear Actuator Simulation/Holder.SLDPRT
100.0 x 40.0 x 10.0 mm

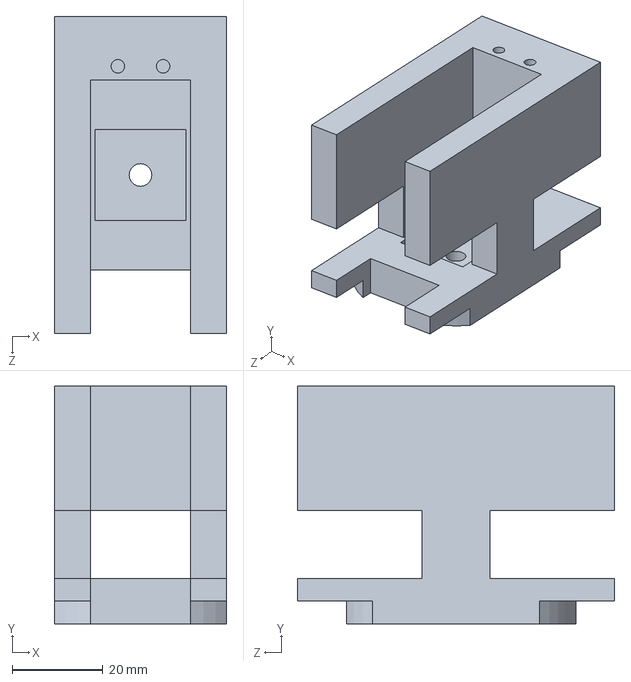
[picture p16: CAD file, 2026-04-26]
hardware/robotic arm/connector_2.SLDPRT
38.0 x 52.5 x 70.0 mm

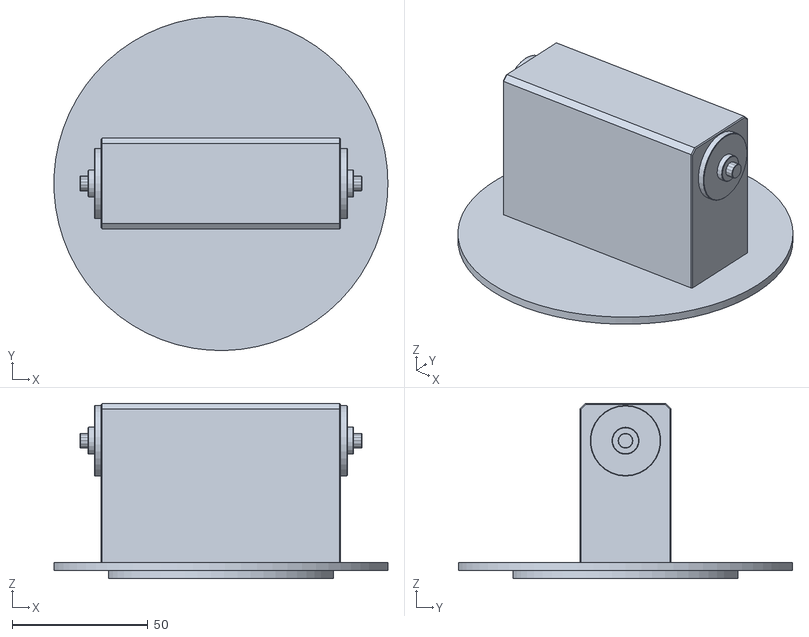
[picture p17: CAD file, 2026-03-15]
workspace/interbotix_ws/src/interbotix_ros_manipulators/interbotix_ros_xsarms/interbotix_xsarm_descriptions/meshes/aloha_vx300s_meshes/shoulder.stl
122.9 x 123.0 x 64.5

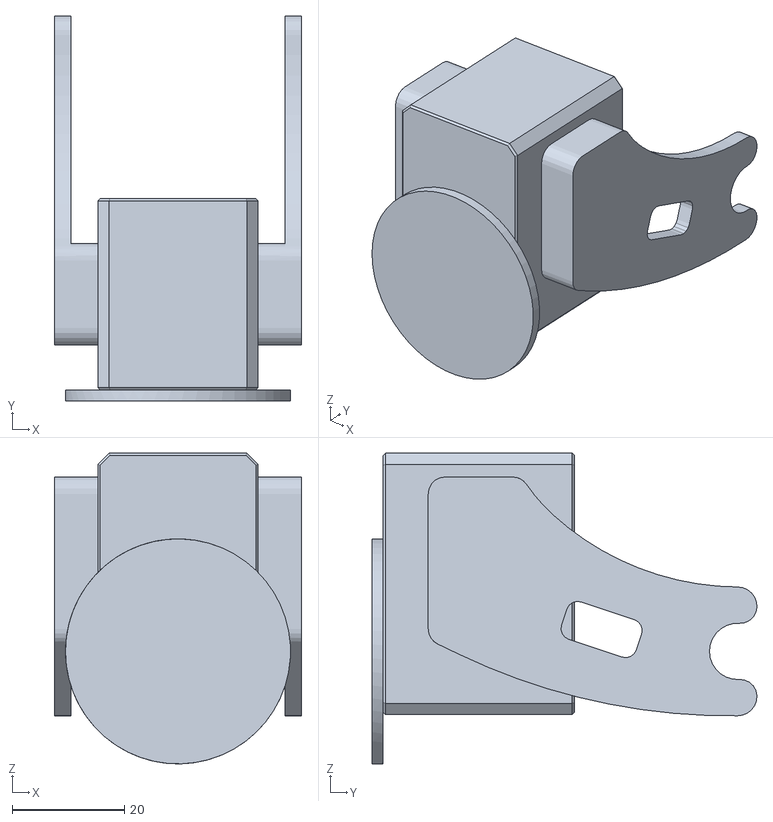
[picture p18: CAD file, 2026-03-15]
workspace/interbotix_ws/src/interbotix_ros_manipulators/interbotix_ros_xsarms/interbotix_xsarm_descriptions/meshes/aloha_wx250s_meshes/wrist.stl
44.0 x 68.4 x 55.2

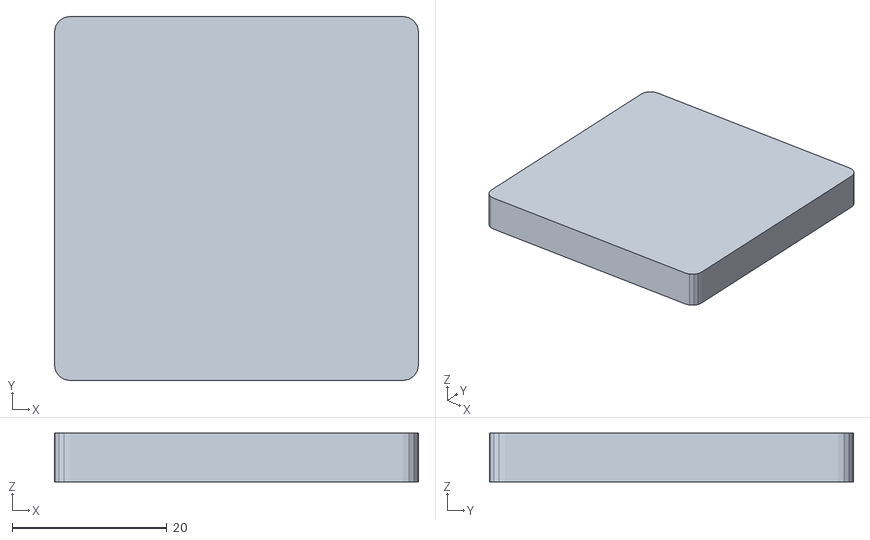
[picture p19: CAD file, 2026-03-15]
workspace/interbotix_ws/src/interbotix_ros_manipulators/interbotix_ros_xsarms/interbotix_xsarm_descriptions/meshes/ar_tag.stl
47.0 x 47.0 x 6.30

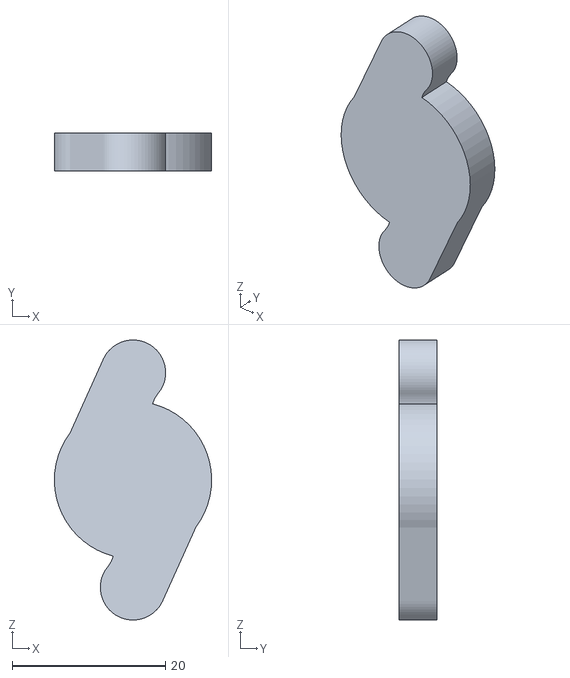
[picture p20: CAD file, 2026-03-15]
workspace/interbotix_ws/src/interbotix_ros_manipulators/interbotix_ros_xsarms/interbotix_xsarm_descriptions/meshes/mobile_px100_meshes/gripper_prop.stl
20.5 x 5.00 x 36.5

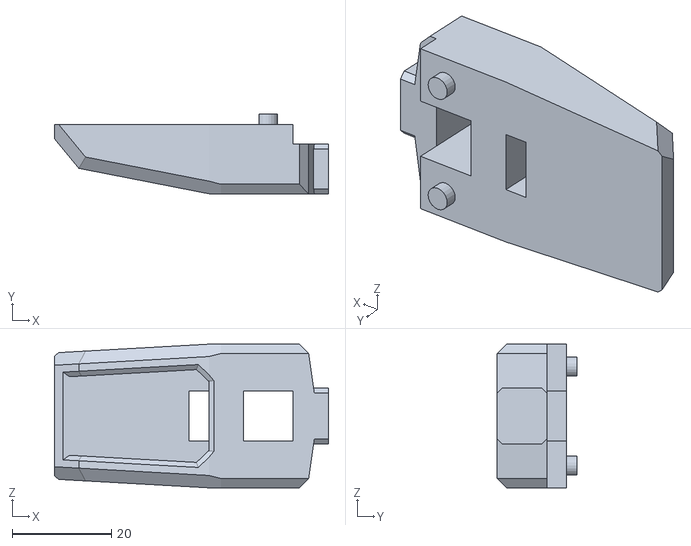
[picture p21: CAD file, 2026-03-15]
workspace/interbotix_ws/src/interbotix_ros_manipulators/interbotix_ros_xsarms/interbotix_xsarm_descriptions/meshes/mobile_wx200_meshes/gripper_finger.stl
55.3 x 16.0 x 29.0

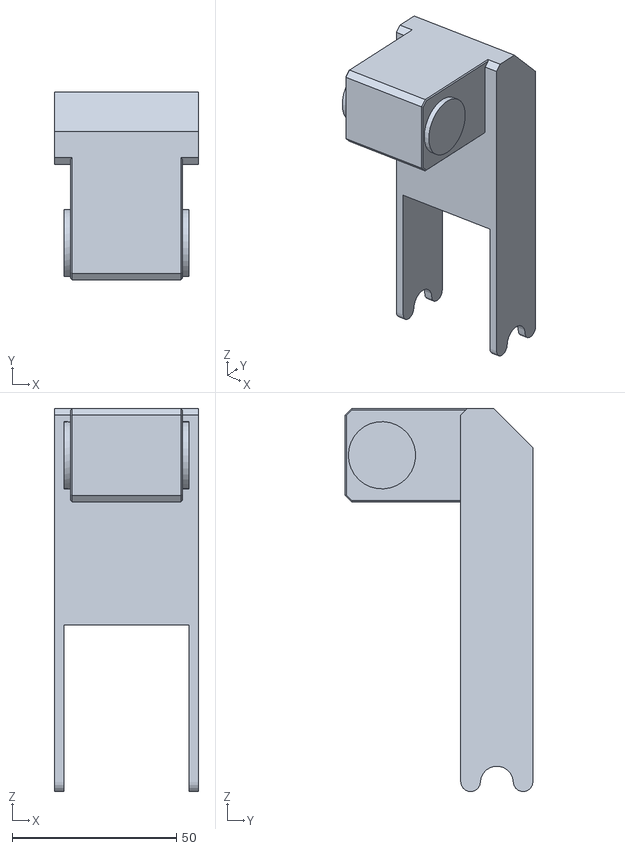
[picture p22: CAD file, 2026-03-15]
workspace/interbotix_ws/src/interbotix_ros_manipulators/interbotix_ros_xsarms/interbotix_xsarm_descriptions/meshes/px100_meshes/upper_arm.stl
44.0 x 57.2 x 116.7

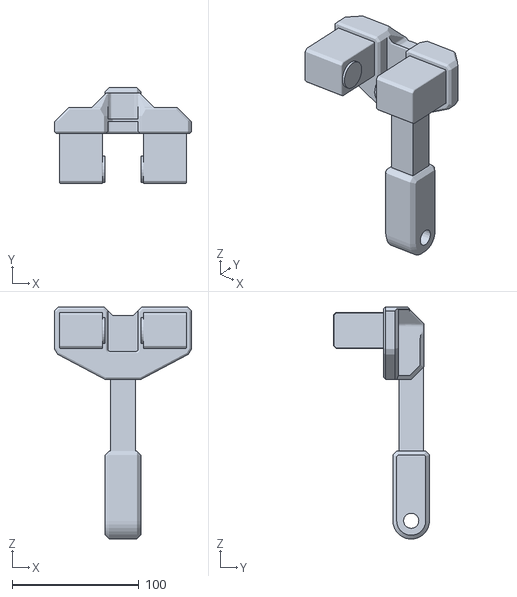
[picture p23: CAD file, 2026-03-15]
workspace/interbotix_ws/src/interbotix_ros_manipulators/interbotix_ros_xsarms/interbotix_xsarm_descriptions/meshes/px150_meshes/upper_arm.stl
108.2 x 75.7 x 182.8

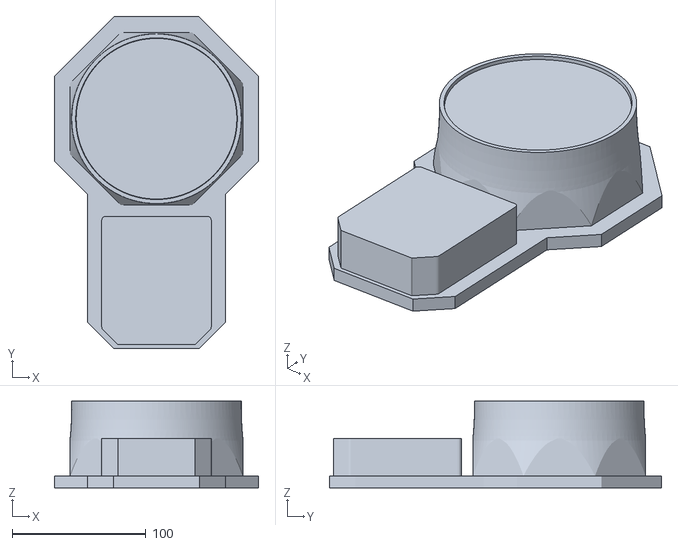
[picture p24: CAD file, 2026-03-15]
workspace/interbotix_ws/src/interbotix_ros_manipulators/interbotix_ros_xsarms/interbotix_xsarm_descriptions/meshes/rx150_meshes/base.stl
153.1 x 248.5 x 65.0

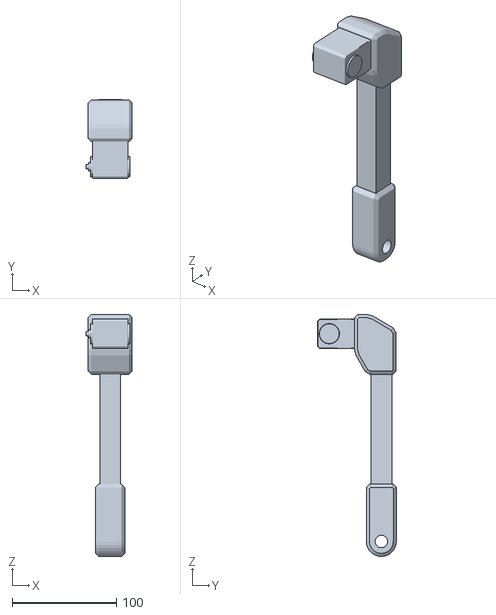
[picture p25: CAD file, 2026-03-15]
workspace/interbotix_ws/src/interbotix_ros_manipulators/interbotix_ros_xsarms/interbotix_xsarm_descriptions/meshes/rx200_meshes/upper_arm.stl
44.5 x 75.7 x 232.5

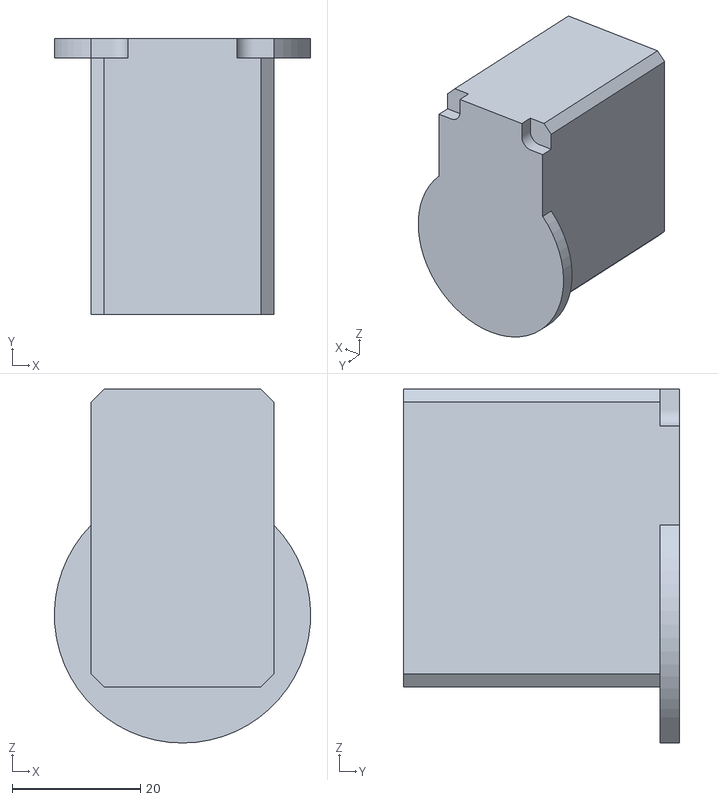
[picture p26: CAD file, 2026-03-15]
workspace/interbotix_ws/src/interbotix_ros_manipulators/interbotix_ros_xsarms/interbotix_xsarm_descriptions/meshes/vx250_meshes/gripper.stl
40.0 x 43.0 x 55.2

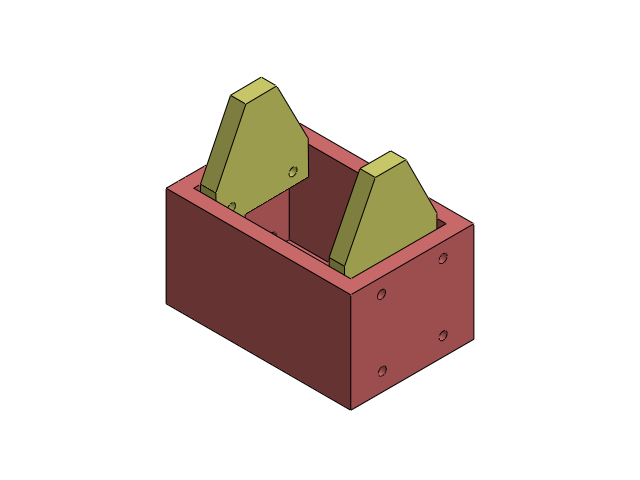
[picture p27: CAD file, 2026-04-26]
hardware/robotic arm/full.SLDASM
gripper_palm
claw x 2
pinion_04_14

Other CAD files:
hardware/Linear Actuator Simulation/Motion Study.SLDASM
hardware/robotic arm/assembly_robotic_arm.SLDASM
hardware/robotic arm/gripper.SLDASM
hardware/Linear Actuator Simulation/Aluminium.SLDPRT
hardware/Linear Actuator Simulation/Base.SLDPRT
hardware/Linear Actuator Simulation/Bearing 688ZZ.SLDPRT
hardware/Linear Actuator Simulation/Carriage.SLDPRT
hardware/Linear Actuator Simulation/Coupling-5x8.SLDPRT
hardware/Linear Actuator Simulation/Hex-M4x25.SLDPRT
hardware/Linear Actuator Simulation/Lead Screw.SLDPRT
hardware/Linear Actuator Simulation/Linear-005.SLDPRT
hardware/Linear Actuator Simulation/Nema23 Step.SLDPRT
hardware/Linear Actuator Simulation/Support.SLDPRT
hardware/Linear Actuator Simulation/Top Base.SLDPRT
hardware/Linear Actuator Simulation/Washer 2.SLDPRT
hardware/Linear Actuator Simulation/Washer.SLDPRT
hardware/robotic arm/20kg_Servo.SLDPRT
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

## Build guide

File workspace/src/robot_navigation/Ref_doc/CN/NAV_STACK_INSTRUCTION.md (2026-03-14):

# Navigation Stack Instruction

## 0. 环境准备

```bash
cd /home/grocerybot/Desktop/EC463_Team_21_Grocery_Robot/workspace
colcon build --symlink-install --packages-select robot_navigation
source /opt/ros/humble/setup.bash
source install/setup.bash
```

后续只重编译这个包时:
```bash
cd /home/grocerybot/Desktop/EC463_Team_21_Grocery_Robot/workspace
colcon build --symlink-install --packages-select robot_navigation
source install/setup.bash
```

## 1. 推荐流程（最稳，直接可用）

### 1.1 建图阶段（会启动 LiDAR + static TF + Cartographer + 串口桥 + EKF）
```bash
ros2 run robot_navigation nav_assistant mapping-stack
```

当前 mapping-stack 默认会在 Cartographer 前面打开一个 `base_link` 裁剪滤波器，
裁剪框是 `x=[-0.2540, 0.1397] m`、`y=[-0.2794, 0.2794] m`、
`z=[-1.0, 1.0] m`，也就是现在这台车后部 `15.5 x 22 in` 的自车回波过滤框。
只有做专项排查时才建议用 `--with-base-link-crop false` 关闭。

D0 参数验证建议直接使用质量配置（PointCloud2 路径）：
```bash
ros2 run robot_navigation nav_assistant mapping-stack \
  --cartographer-config-basename pico_2d_mapping_quality.lua
```

可视化版本:
```bash
ros2 run robot_navigation nav_assistant mapping-stack --with-rviz true
```

### 1.2 手动遥控
```bash
ros2 run robot_navigation nav_assistant teleop
```

### 1.3 保存 + 导出地图（推荐导出分辨率 0.03）
```bash
ros2 run robot_navigation nav_assistant save-map --map-name testmapMain
ros2 run robot_navigation nav_assistant export-map --map-name testmapMain --resolution 0.03
```

### 1.4 定位 + Nav2 阶段（会启动 LiDAR + static TF + 串口桥 + EKF + Cartographer localization + map_server + Nav2）
当前工作命令:

```bash
cd /home/grocerybot/Desktop/EC463_Team_21_Grocery_Robot/workspace
source /opt/ros/humble/setup.bash
source install/setup.bash
ros2 run robot_navigation nav_assistant localization-stack --map-name testmapMain --with-nav2-rviz true
```

等价的直接 launch 版本:
```bash
ros2 launch robot_navigation nav2_localization_stack.launch.py \
  pbstream_file:=/home/grocerybot/Desktop/EC463_Team_21_Grocery_Robot/Maps/testmapMain.pbstream \
  map_yaml:=/home/grocerybot/Desktop/EC463_Team_21_Grocery_Robot/Maps/testmapMain.yaml \
  nav2_params_file:=/home/grocerybot/Desktop/EC463_Team_21_Grocery_Robot/workspace/src/robot_navigation/config/nav2_params_smac_mppi_omni.yaml \
  with_nav2_rviz:=true
```

说明：这个裁剪滤波只清理 Cartographer 的点云输入，不替代 Nav2 自己的
robot footprint / robot box。
Localization + Nav2 默认保持裁剪关闭，只有你显式传
`--with-base-link-crop true` 时才会打开。
当前 Nav2 默认参数文件是 `nav2_params_smac_mppi_omni.yaml`，
也就是 `SmacPlanner2D + MPPIController(Omni)` 这套组合。

### 1.5 命令行发导航目标
```bash
ros2 run robot_navigation nav_assistant goal --x 1.0 --y 0.0 --yaw 0.0
```

多点:
```bash
ros2 run robot_navigation nav_assistant waypoints \
  --pose 1.0,0.0,0.0 \
  --pose 1.5,0.5,0.0 \
  --pose 0.5,1.0,0.0
```

## 2. 按组件分开启动（调试模式）

以下用于单独排查节点问题，不是日常首选。

### 2.1 SICK LiDAR 驱动
```bash
ros2 run sick_scan_xd sick_generic_caller \
  $(ros2 pkg prefix sick_scan_xd)/share/sick_scan_xd/launch/sick_picoscan.launch \
  hostname:=192.168.8.150 \
  udp_receiver_ip:=192.168.8.249 \
  publish_frame_id:=lidar_link \
  publish_imu_frame_id:=imu_link \
  tf_publish_rate:=0.0 \
  imu_udp_port:=7503 \
  scandataformat:=2 \
  send_sopas_start_stop_cmd:=0 \
  host_set_FREchoFilter:=0 \
  host_set_LFPangleRangeFilter:=0 \
  host_set_LFPintervalFilter:=0 \
  custom_pointclouds:=cloud_all_fields_fullframe \
  cloud_all_fields_fullframe:='coordinateNotation=3 updateMethod=0 fields=x,y,z,i,range,azimuth,elevation,t,ts,lidar_sec,lidar_nsec,ring,layer,echo,reflector echos=0,1,2 layers=1,2,3,4,5,6,7,8,9,10,11,12,13,14,15,16 reflectors=0,1 infringed=0,1 rangeFilter=0,999,0 topic=/cloud_all_fields_fullframe frameid=lidar_link publish=1' \
  imu_topic:=/sick_scansegment_xd/imu
```

### 2.2 static TF (`base_link -> lidar_link`, `lidar_link -> imu_link`)
```bash
ros2 run tf2_ros static_transform_publisher \
  --x 0.2413 --y 0.0 --z 0.0 \
  --roll 0.0 --pitch 0.0 --yaw 0.0 \
  --frame-id base_link --child-frame-id lidar_link
```

```bash
ros2 run tf2_ros static_transform_publisher \
  --x 0.0124 --y 0.0185 --z -0.0484 \
  --roll 0.0 --pitch 0.0 --yaw 0.0 \
  --frame-id lidar_link --child-frame-id imu_link
```

Notes:

- 当前项目预设按你的安装假设处理：`lidar_link` 取 bracket 中心，且该中心与当前 project 的 optical-origin proxy 视为同一点。
- `0.2413 m` 来自 `20 in / 2 - 1 in / 2 = 9.5 in = 0.2413 m`，也就是 20 英寸底盘半宽减去标准 1 英寸 80/20 前横梁半宽。
- `0.0124, 0.0185, -0.0484 m` comes from the SICK operating instructions as IMU position relative to the optical origin.

### 2.3 Cartographer mapping
```bash
ros2 launch robot_navigation cartographer_mapping.launch.py
```

说明：单独直接起 `cartographer_mapping.launch.py` 时，不会自动带上默认裁剪滤波。
完整 mapping stack 里，Cartographer 实际接的是经过 `base_link` 裁剪后的
`/cloud_all_fields_fullframe_filtered`。

### 2.4 Cartographer localization
```bash
ros2 launch robot_navigation cartographer_localization.launch.py \
  load_state_filename:=/home/grocerybot/Desktop/EC463_Team_21_Grocery_Robot/Maps/testmapMain.pbstream \
  configuration_basename:=pico_2d_localization.lua
```

### 2.5 串口桥（STM32 -> /odom_raw）
```bash
ros2 run robot_navigation nav2_serial_bridge --ros-args \
  -p serial_port:=/dev/ttyUSB0 \
  -p baud_rate:=115200 \
  -p cmd_topics:='["/cmd_vel","/cmd_vel_nav","/cmd_vel_smoothed"]' \
  -p odom_topic:=/odom_raw \
  -p frame_id:=odom \
  -p child_frame_id:=base_link \
  -p publish_tf:=false \
  -p fallback_odom:=false
```

### 2.6 EKF（/odom_raw + IMU -> /odom）
```bash
ros2 run robot_localization ekf_node --ros-args \
  --params-file <repo_root>/workspace/src/robot_navigation/config/ekf_odom_base_imu.yaml \
  -r odometry/filtered:=/odom
```

### 2.7 map_server + lifecycle
```bash
ros2 run nav2_map_server map_server --ros-args \
  -p yaml_filename:=/home/grocerybot/Desktop/EC463_Team_21_Grocery_Robot/Maps/testmapMain.yaml
```

```bash
ros2 run nav2_lifecycle_manager lifecycle_manager --ros-args \
  -p autostart:=true \
  -p node_names:="[map_server]"
```

### 2.8 Nav2 bringup
```bash
ros2 launch nav2_bringup navigation_launch.py \
  params_file:=/home/grocerybot/Desktop/EC463_Team_21_Grocery_Robot/workspace/src/robot_navigation/config/nav2_params_smac_mppi_omni.yaml
```

## 3. 常用检查命令

```bash
ros2 run robot_navigation nav_assistant quick-check
ros2 node info /cartographer_node | grep points2
ros2 topic hz /odom
ros2 topic hz /cloud_all_fields_fullframe
ros2 action list | grep navigate_to_pose
```

## 4. 你当前代码里的关键默认值（便于对照）

- `odom_topic` 默认: `/odom_raw`
- `use_ekf` 默认: `true`
- `fallback_odom` 默认: `false`
- LiDAR frame 默认: `lidar_link`
- static TF 默认: `base_link -> lidar_link = (0.2413, 0, 0, 0, 0, 0)`
- `mapping-stack with_base_link_crop` 默认: `true`
- `localization-stack with_base_link_crop` 默认: `false`
- Cartographer 裁剪框默认:
  `x=[-0.2540, 0.1397] m`、`y=[-0.2794, 0.2794] m`、`z=[-1.0, 1.0] m`
- Nav2 的 footprint / robot box 仍然独立于这个裁剪逻辑
- Nav2 默认参数文件: `config/nav2_params_smac_mppi_omni.yaml`
- 当前 planner/controller: `SmacPlanner2D + MPPIController(Omni)`
- `localization-stack cmd_topics` 默认: `["/cmd_vel"]`
- `with_nav2_rviz` 默认: `false`

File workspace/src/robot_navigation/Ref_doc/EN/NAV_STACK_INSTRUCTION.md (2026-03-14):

# Navigation Stack Instruction

## 0. Environment setup

```bash
cd /home/grocerybot/Desktop/EC463_Team_21_Grocery_Robot/workspace
colcon build --symlink-install --packages-select robot_navigation
source /opt/ros/humble/setup.bash
source install/setup.bash
```

Rebuild only this package later:
```bash
cd /home/grocerybot/Desktop/EC463_Team_21_Grocery_Robot/workspace
colcon build --symlink-install --packages-select robot_navigation
source install/setup.bash
```

## 1. Recommended workflow (primary path)

### 1.1 Mapping phase
Starts: LiDAR, static TF, Cartographer mapping, serial bridge, EKF.

```bash
ros2 run robot_navigation nav_assistant mapping-stack
```

Default mapping-stack behavior now enables a `base_link` crop filter before
Cartographer with `x=[-0.2540, 0.1397] m`, `y=[-0.2794, 0.2794] m`,
`z=[-1.0, 1.0] m`, i.e. the current rear `15.5 x 22 in` self-hit filter box.
Disable it only for debugging with `--with-base-link-crop false`.

For D0 parameter validation (PointCloud2 path), use the quality config directly:
```bash
ros2 run robot_navigation nav_assistant mapping-stack \
  --cartographer-config-basename pico_2d_mapping_quality.lua
```

With RViz:
```bash
ros2 run robot_navigation nav_assistant mapping-stack --with-rviz true
```

### 1.2 Manual driving
```bash
ros2 run robot_navigation nav_assistant teleop
```

### 1.3 Save and export map
```bash
ros2 run robot_navigation nav_assistant save-map --map-name testmapMain
ros2 run robot_navigation nav_assistant export-map --map-name testmapMain
```

### 1.4 Localization + Nav2 phase
Starts: LiDAR, static TF, serial bridge, EKF, Cartographer localization, map_server, Nav2.

Current working command:

```bash
cd /home/grocerybot/Desktop/EC463_Team_21_Grocery_Robot/workspace
source /opt/ros/humble/setup.bash
source install/setup.bash
ros2 run robot_navigation nav_assistant localization-stack --map-name testmapMain --with-nav2-rviz true
```

Equivalent direct launch:
```bash
ros2 launch robot_navigation nav2_localization_stack.launch.py \
  pbstream_file:=/home/grocerybot/Desktop/EC463_Team_21_Grocery_Robot/Maps/testmapMain.pbstream \
  map_yaml:=/home/grocerybot/Desktop/EC463_Team_21_Grocery_Robot/Maps/testmapMain.yaml \
  nav2_params_file:=/home/grocerybot/Desktop/EC463_Team_21_Grocery_Robot/workspace/src/robot_navigation/config/nav2_params_smac_mppi_omni.yaml \
  with_nav2_rviz:=true
```

Note: this crop filter cleans Cartographer's point-cloud input path only.
Nav2 still uses its own robot footprint/box for planning and collision logic.
Localization + Nav2 keeps crop disabled by default unless you pass
`--with-base-link-crop true`.
Current Nav2 stack defaults to `nav2_params_smac_mppi_omni.yaml`
(`SmacPlanner2D + MPPIController(Omni)`).

### 1.5 Send goals from CLI
```bash
ros2 run robot_navigation nav_assistant goal --x 1.0 --y 0.0 --yaw 0.0
```

Waypoints:
```bash
ros2 run robot_navigation nav_assistant waypoints \
  --pose 1.0,0.0,0.0 \
  --pose 1.5,0.5,0.0 \
  --pose 0.5,1.0,0.0
```

## 2. Component-by-component startup (debug mode)

Use these only when you need isolated debugging.

### 2.1 SICK LiDAR driver
```bash
ros2 run sick_scan_xd sick_generic_caller \
  $(ros2 pkg prefix sick_scan_xd)/share/sick_scan_xd/launch/sick_picoscan.launch \
  hostname:=192.168.8.150 \
  udp_receiver_ip:=192.168.8.249 \
  publish_frame_id:=lidar_link \
  publish_imu_frame_id:=imu_link \
  tf_publish_rate:=0.0 \
  imu_udp_port:=7503 \
  scandataformat:=2 \
  send_sopas_start_stop_cmd:=0 \
  host_set_FREchoFilter:=0 \
  host_set_LFPangleRangeFilter:=0 \
  host_set_LFPintervalFilter:=0 \
  custom_pointclouds:=cloud_all_fields_fullframe \
  cloud_all_fields_fullframe:='coordinateNotation=3 updateMethod=0 fields=x,y,z,i,range,azimuth,elevation,t,ts,lidar_sec,lidar_nsec,ring,layer,echo,reflector echos=0,1,2 layers=1,2,3,4,5,6,7,8,9,10,11,12,13,14,15,16 reflectors=0,1 infringed=0,1 rangeFilter=0,999,0 topic=/cloud_all_fields_fullframe frameid=lidar_link publish=1' \
  imu_topic:=/sick_scansegment_xd/imu
```

### 2.2 Static TF (`base_link -> lidar_link`, `lidar_link -> imu_link`)
```bash
ros2 run tf2_ros static_transform_publisher \
  --x 0.2413 --y 0.0 --z 0.0 \
  --roll 0.0 --pitch 0.0 --yaw 0.0 \
  --frame-id base_link --child-frame-id lidar_link
```

```bash
ros2 run tf2_ros static_transform_publisher \
  --x 0.0124 --y 0.0185 --z -0.0484 \
  --roll 0.0 --pitch 0.0 --yaw 0.0 \
  --frame-id lidar_link --child-frame-id imu_link
```

Notes:

- Current project preset follows the user-validated mount assumption: `lidar_link` is modeled at the bracket center and used as the project's optical-origin proxy.
- `0.2413 m` comes from `20 in / 2 - 1 in / 2 = 9.5 in = 0.2413 m`, i.e. half the 20 in base minus half the standard 1.00 in 80/20 front bar width.
- `0.0124, 0.0185, -0.0484 m` comes from the SICK operating instructions as IMU position relative to the optical origin.

### 2.3 Cartographer mapping
```bash
ros2 launch robot_navigation cartographer_mapping.launch.py
```

Note: `cartographer_mapping.launch.py` alone does not start the default crop
filter. In the full mapping stack, Cartographer receives
`/cloud_all_fields_fullframe_filtered` after the `base_link` crop filter.

### 2.4 Cartographer localization
```bash
ros2 launch robot_navigation cartographer_localization.launch.py \
  load_state_filename:=/home/grocerybot/Desktop/EC463_Team_21_Grocery_Robot/Maps/testmapMain.pbstream \
  configuration_basename:=pico_2d_localization.lua
```

### 2.5 Serial bridge (`STM32 -> /odom_raw`)
```bash
ros2 run robot_navigation nav2_serial_bridge --ros-args \
  -p serial_port:=/dev/ttyUSB0 \
  -p baud_rate:=115200 \
  -p cmd_topics:='["/cmd_vel","/cmd_vel_nav","/cmd_vel_smoothed"]' \
  -p odom_topic:=/odom_raw \
  -p frame_id:=odom \
  -p child_frame_id:=base_link \
  -p publish_tf:=false \
  -p fallback_odom:=false
```

### 2.6 EKF (`/odom_raw + IMU -> /odom`)
```bash
ros2 run robot_localization ekf_node --ros-args \
  --params-file <repo_root>/workspace/src/robot_navigation/config/ekf_odom_base_imu.yaml \
  -r odometry/filtered:=/odom
```

### 2.7 map_server + lifecycle manager
```bash
ros2 run nav2_map_server map_server --ros-args \
  -p yaml_filename:=/home/grocerybot/Desktop/EC463_Team_21_Grocery_Robot/Maps/testmapMain.yaml
```

```bash
ros2 run nav2_lifecycle_manager lifecycle_manager --ros-args \
  -p autostart:=true \
  -p node_names:="[map_server]"
```

### 2.8 Nav2 bringup
```bash
ros2 launch nav2_bringup navigation_launch.py \
  params_file:=/home/grocerybot/Desktop/EC463_Team_21_Grocery_Robot/workspace/src/robot_navigation/config/nav2_params_smac_mppi_omni.yaml
```

## 3. Common health checks

```bash
ros2 run robot_navigation nav_assistant quick-check
ros2 node info /cartographer_node | grep points2
ros2 topic hz /odom
ros2 topic hz /cloud_all_fields_fullframe
ros2 action list | grep navigate_to_pose
```

## 4. Current key defaults (for quick reference)

- `odom_topic`: `/odom_raw`
- `use_ekf`: `true`
- `fallback_odom`: `false`
- LiDAR frame: `lidar_link`
- Static TF default: `base_link -> lidar_link = (0.2413, 0, 0, 0, 0, 0)`
- `mapping-stack with_base_link_crop`: `true`
- `localization-stack with_base_link_crop`: `false`
- Cartographer crop box:
  `x=[-0.2540, 0.1397] m`, `y=[-0.2794, 0.2794] m`, `z=[-1.0, 1.0] m`
- Nav2 footprint/robot box remains separate from this crop behavior
- Default Nav2 params file: `config/nav2_params_smac_mppi_omni.yaml`
- Current planner/controller: `SmacPlanner2D + MPPIController(Omni)`
- `localization-stack cmd_topics`: `["/cmd_vel"]`
- `with_nav2_rviz`: `false`

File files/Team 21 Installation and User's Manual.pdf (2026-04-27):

## 1. Overview

GOFR, the Grocery Operations and Fulfillment Robot, is a full-stack robotic grocery assistant designed to support order fulfillment and store-side item handling. It combines a mecanum-drive mobile base, LiDAR-based navigation, a ViperX/VX300S robotic arm, RealSense vision, local ultrasonic sensing, ROS 2 task orchestration, a Node.js/PostgreSQL backend, and browser-based user interfaces.

The intent of this document is to bring a new user, store operator, or maintainer up to speed so that they can install, start, operate, stop, and recover the product. The installation section assumes that the robot may be moved to another indoor test area or store-like aisle. The User's Manual assumes that setup has already been completed and focuses on safe operation by customer, store employee, and maintainer roles.

This document should be reviewed during customer handoff. The installer should walk the client through the physical stop controls, Fleet Manager pages, customer ordering flow, semantic map editing workflow, and maintainer diagnostic checks before allowing normal operation.

## 2. System Overview

Author source: Pree for the high-level system description and interfaces; Darren for the physical chassis description; Bach for the custom robotic-arm prototype description; Lion for final consolidation and technical expansion.

2.1 Major Subsystems
GOFR is a full-stack robotic system with the following major subsystems:
- Mobile base: mecanum-drive chassis controlled by an STM32 motor-control board.
- Navigation stack: ROS 2 Humble, Cartographer, EKF-based odometry fusion, and Nav2.
- Manipulation stack: Interbotix ViperX/VX300S arm with MoveIt 2 and a ROS action server.
- Vision stack: Intel RealSense camera with YOLO-based detection and target pose publication.
- Safety sensing: ESP32-based ultrasonic sensor nodes publishing four-direction collision alerts.
- Backend and UI: Node.js + PostgreSQL backend with a customer web app and employee fleet dashboard using the Vue.js framework.
- Task orchestration: ROS 2 Behavior Trees that connect orders, semantic targets, navigation, vision, and arm control.

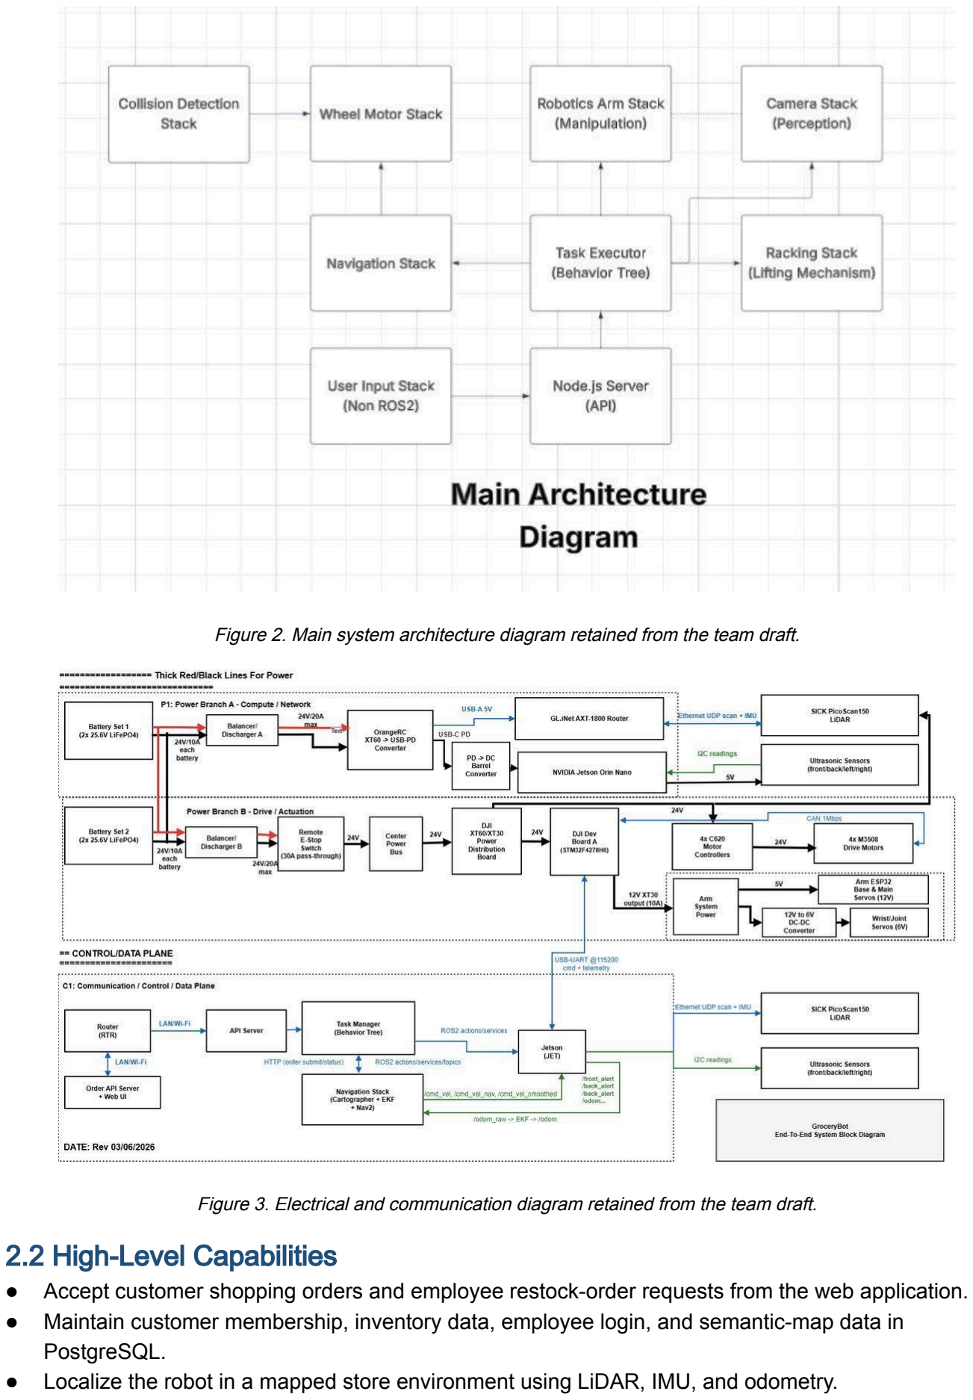
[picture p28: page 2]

Figure 2. Main system architecture diagram retained from the team draft.

Figure 3. Electrical and communication diagram retained from the team draft.

2.2 High-Level Capabilities
- Accept customer shopping orders and employee restock-order requests from the web application.
- Maintain customer membership, inventory data, employee login, and semantic-map data in PostgreSQL.
- Localize the robot in a mapped store environment using LiDAR, IMU, and odometry.

- Dynamically adjust product locations on the map using the Fleet Manager Store Map workflow.
- Navigate to a selected aisle, rack, or product slot location.
- Detect and verify a target object using RealSense and YOLO.
- Command the ViperX arm to pick and place an item.
- Show store-map and SLAM-related views in the employee-facing interface.
- Provide AI-assisted and multilingual support in both applications when the Gemini API path is configured.

2.3 User-Facing Interfaces

Interface | Primary user | Purpose
Customer web interface | Customer or demo user | Browser-based shopping interface served by the backend. It supports member login or guest flow, inventory browsing, cart building, order submission, multilingual page variants, and an optional AI assistant panel.
Employee Fleet Manager dashboard | Store employee or operator | Vue-based dashboard for inventory reports, semantic Store Map editing, SLAM viewing, robot status, restock submission, employee accounts, and AI-assisted interaction.
JetKVM remote console | Maintainer or integration operator | Remote console for the JetPack / robot host. Used for software installation, ROS commands, mapping, diagnostics, and recovery.

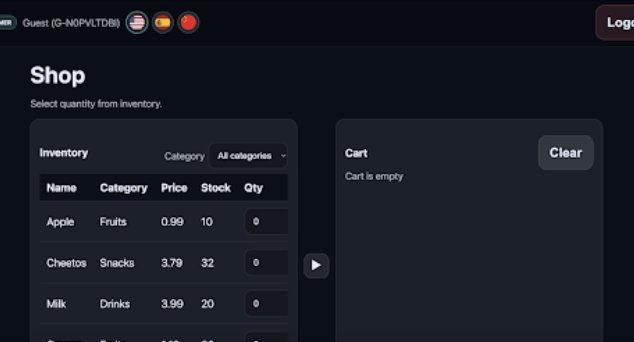
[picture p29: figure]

Figure 4. Customer shopping interface example retained from the team draft.

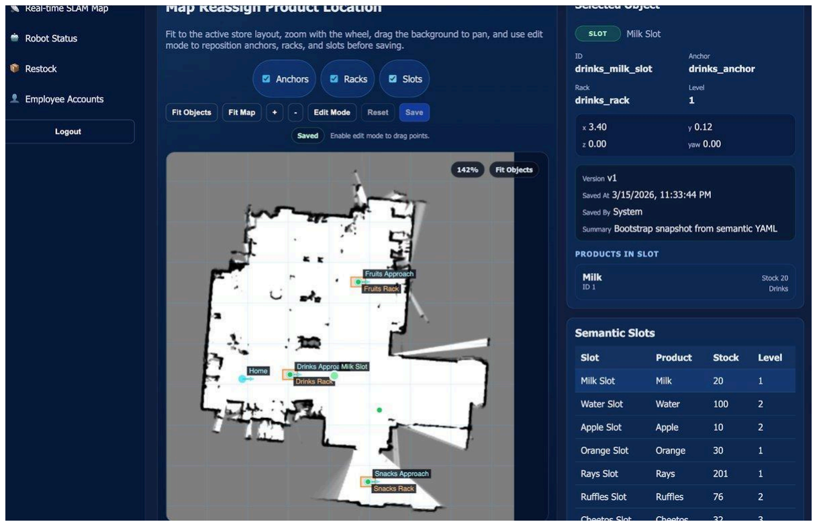
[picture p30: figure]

Figure 5. Fleet Manager / map-related interface example retained from the team draft.

2.4 Physical Description of the Robot
Darren: The 20 inch by 20 inch chassis is made of 10-series 8020 and includes two main layers. The first layer houses most of the electrical components of the robot, including the LiDAR, motors, batteries, and Jetson-class robot computer. Four 6 inch mecanum wheels are used. These components are placed into 3D-printed housings and mounted on a 0.125 inch by 14 inch by 14 inch aluminum plate. The second layer is elevated 10 inches above the first layer and includes a GeekPi 9 inch LCD monitor, ViperX 300S robotic arm, and basket for holding groceries.

Darren: Acrylic plates are used as the outer casing along with 3D-printed parts that slide into the 8020 bars. The slots in these printed parts allow users to slide the acrylic plates in and out for easier assembly and disassembly.

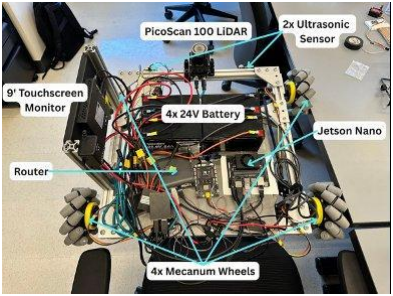
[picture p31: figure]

Figure 6. Annotated physical components from the team draft.

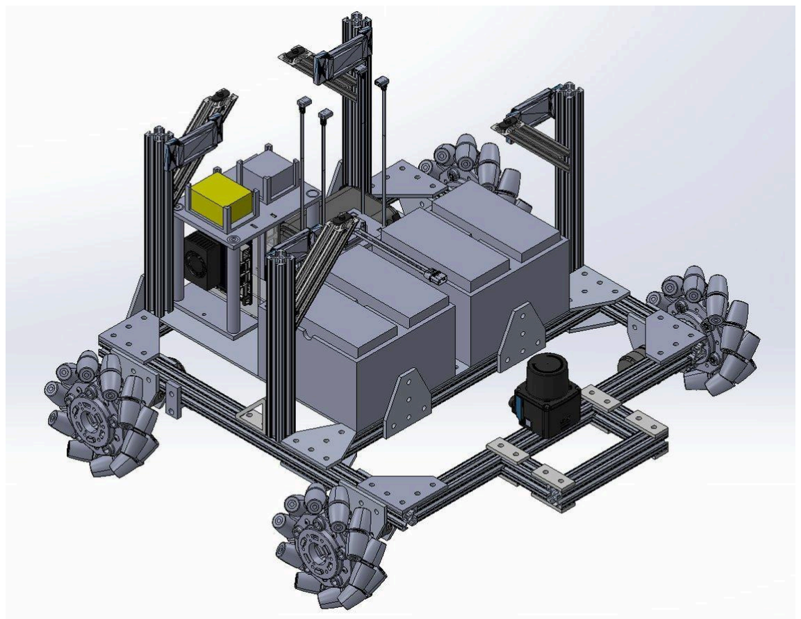
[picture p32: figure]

Figure 7. CAD view of the GOFR chassis.

2.5 Custom Robotic Arm Prototype
Bach: The custom robotic arm is built using 3D-printed components, 8020 linkages, a turntable bearing, and servo motors. Major components such as the base and gripper were 3D printed because this fabrication process is fast and highly customizable. The 8020 linkages improve modularity because arm reach can be adjusted by changing linkage length. The 8020 built-in connection hubs also simplify assembly by reducing the need for drilling or designing extra connection layers. To maximize strength-to-weight ratio and minimize weight, multiple servo motors with different torque ratings were selected.

Prototype boundary: The custom arm is documented for team continuity and future work. The full-system operation described in this manual uses the ViperX/VX300S arm path.

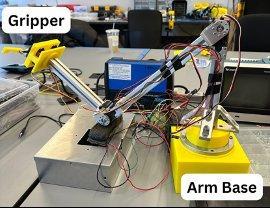
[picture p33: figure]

Figure 8. Custom robotic-arm prototype retained from the team draft.

## 3. Product Setup and Installation

Author source: Darren for hardware assembly; Lion (Xingjian Jiang) for software installation, runtime bring-up, mapping, readiness checks, and integration boundaries. This section explains what another team, maintainer, or store-side operator needs in order to set up GOFR in a new location. After completing these steps, the robot should be ready for the operating procedures described in the User's Manual.

3.1 Start Here: Bring-Up Map

Step | Stage | Exit condition
1 | Place and inspect | Place GOFR in a clear indoor test area. Check frame, wiring, batteries, emergency stop, ViperX arm, RealSense camera, PicoScan LiDAR, and ultrasonic sensors.
2 | Connect hardware | Connect robot computer, STM32 base controller, ESP32 ultrasonic boards, ViperX arm controller, RealSense camera, and PicoScan LiDAR.
3 | Open JetKVM | From a maintenance laptop on the robot network, open http://192.168.8.113 and control the JetPack / robot-host desktop.
4 | Verify firmware | Flash or verify STM32 base-control firmware and ESP32 ultrasonic firmware.
5 | Install host software | Install Linux dependencies, ROS 2 Humble, Node.js, npm, PostgreSQL, Interbotix/ViperX dependencies, RealSense dependencies, and build tools.
6 | Build workspaces | Build the Interbotix workspace first, then the GOFR ROS 2 workspace.
7 | Provision backend | Create PostgreSQL database, load schema/seed data, configure backend credentials, and optionally add a Gemini API key.
8 | Create or load map | Create the base navigation map for the current room/store or verify the existing map matches the physical layout.
9 | Align semantic layout | Use Fleet Manager Store Map to align the home anchor, rack anchors, racks, and product slots.
10 | Start runtime stack | Start backend, Fleet Manager UI, navigation, optional rosbridge, ViperX arm stack, camera vision node, and Behavior Tree executor.
11 | Run readiness checks | Verify actions, services, topics, UI, semantic map, remote power switches, and E-stop before creating a pickup order.
12 | Run first test order | Submit one item such as Apple, Green Tea, Water, Orange, Lemon, Can, or Bag of Chips.

Bring-up rule: There is not currently a single full-system launch command that starts every service. The staged sequence above is the reliable installation path because each subsystem can be verified before the next one is started.

3.2 What's in the Box: System Components

Component | Installation purpose

GOFR mobile chassis | Main robot frame, payload platform, and mounting base for electronics and arm.
Mecanum wheels | Omnidirectional mobile-base movement for aisle alignment and lateral adjustment.
Aluminum frame, acrylic plates, PETG printed parts | Robot structure, protective covers, and sensor/electronics mounting.
ViperX/VX300S robotic arm | Primary validated manipulation path for product pickup and basket placement.
Intel RealSense camera | Product detection, depth sensing, and visual input for the pickup pipeline.
SICK PicoScan LiDAR | Mapping, localization, and navigation sensing.
STM32 base controller | Motor-control and odometry/telemetry bridge between ROS and the mecanum drive.
DJI C620 motor controllers and M3508 motors | Drive system for the four-wheel mecanum base.
ESP32 ultrasonic boards and ultrasonic sensors | Local front/left/right/rear collision-alert sensing.
Robot computer / JetPack host | Runs ROS 2, navigation, vision, manipulation, and task-management software.
Router or local network device | Connects robot services, operator UI, JetKVM, LiDAR, and maintenance laptop.
Batteries and power distribution | Separated compute/network and drive/actuation power branches.
Remote emergency stop | Stops unsafe motion by cutting or disabling the drive/actuation branch.
Two infrared remote power switches | Remote enable/disable controls for the control/compute branch and drive/actuation branch.

Power-branch assumption: The installation assumes separated compute/network and drive/actuation branches. This allows compute to remain available for diagnostics after the drive-side emergency stop has been pressed.

3.3 Hardware Contents from Team Draft

Category | Items
8020 parts | Partially completed first layer; partially completed second layer; 4x 8020-4140; 2x 10.125 in 8020-10; 2x 10 in 8020-10; 4x M3508 holder front; 4x M3508 holder back; 2x 8020-4136; 4x 8020-4151.
Electrical components | 4x DJI M3508 motors; 1x Jetson Nano / robot computer; 1x PicoScan LiDAR and mount; 1x JetKVM; 1x Orange RC XT60; 1x JetKVM switch extension port; 1x DJI devboard; 4x batteries; 4x C620 DC controllers; 1x M3508 terminal board; 1x GL.iNet AX1800 wireless router; 1x ViperX 300S robotic arm; 4x ESP32; 6x ultrasonic sensors.
3D-printed parts | 2x battery holders; 1x Clustercase; 1x motor driver holder; 1x router holder; 2x charging port; 1x front casing; right/left/front/back/top acrylic sliders; back/front/right/left ultrasonic sensor holders.
Casing and plates | 1x 0.125 in x 14 in x 14 in aluminum plate; 1x 0.125 in x 14 in x 16 in aluminum plate; 2x 0.125 in x 10.32 in x 9 in white acrylic plate; 1x 0.125 in x 9 in x 18.3 in white acrylic plate; 1x 0.125 in x 9.5 in x 12.25 in white acrylic plate; 2x 0.125 in x 9.3 in x 3.1 in white acrylic plate.

3.4 Software System Components

Software component | Location | Purpose
Backend API | order-api-postgre | Orders, inventory, users, product data, and semantic map data.
Fleet Manager UI | order-api-postgre/fleet-manager | Operator dashboard, inventory/map views, and Store Map editor.

Navigation package | workspace/src/robot_navigation | LiDAR, Cartographer, Nav2, semantic map, STM32 bridge, and helper CLI.
Task manager package | workspace/src/robot_task_manager | Behavior Tree order execution and full pickup orchestration.
Manipulation package | workspace/src/robot_manipulation | ViperX/VX300S MoveIt stack and /pick_viperx action server.
Vision package | workspace/src/robot_vision | RealSense/YOLO detection and /detections_json topic.
Perception package | workspace/src/robot_perception | Ultrasonic alert topics and local collision sensing integration.
Shared ROS interfaces | workspace/src/robot_interfaces | Custom ROS messages, services, and actions.
ESP32 firmware | ESP32 | Ultrasonic and actuator-side firmware projects.
STM32 firmware | STM32 | Mobile-base firmware.
Map assets | Maps | Saved navigation maps such as .pbstream, .yaml, and .pgm files.
Semantic map | workspace/src/robot_navigation/config/sem antic_map_testmapMain.yaml | Home anchor, approach anchors, racks, slots, navigation poses, and service poses.

3.5 Supporting Equipment and Environment
- Indoor floor area with enough clearance for base motion and arm motion.
- Table, shelf fixture, or test rack for first pickup tests.
- Linux robot host capable of running ROS 2 Humble.
- Maintenance laptop connected to the same robot network.
- JetKVM remote console access to the JetPack / robot host.
- Stable Wi-Fi or Ethernet between the robot, operator computer, JetKVM, and LiDAR network.
- USB access to the STM32, ViperX arm controller, ESP32 boards, and RealSense camera.
- STM32CubeIDE or a compatible STM32 flashing tool.
- ESP-IDF for ESP32 firmware projects and Arduino IDE with ESP32 board support for sketch-level tests.
- PostgreSQL installed locally on the robot/backend host, or Docker Desktop if using the Windows backend test option.
- An operator standing near the emergency stop during all first base-motion and arm-motion tests. Safety gate: Do not run autonomous navigation or arm pickup until manual stop behavior has been verified. During early tests, the E-stop operator should not also be the person typing commands.

3.6 User and Maintenance Interfaces

Interface | Intended user | Purpose
Customer app | Customer or demo user | Create a shopping/pickup request and view order progress.
Fleet Manager UI | Store employee or operator | Manage inventory/map views, monitor tasks, and prepare store-side operation.
JetKVM remote console | Maintainer or integration operator | Configure JetPack, run terminals, build software, create maps, and run ROS checks.
Infrared remote switches and E-stop controls | Setup operator or safety observer | Enable/disable control and drive/actuation power branches and stop unsafe motion.

3.7 Accounts, Network Settings, and Credentials

Item | Current/default value
Backend URL | http://localhost:3000
Fleet UI URL | http://localhost:5174
Customer app URL | Deployment-specific; record during installation handoff.
JetKVM management URL | http://192.168.8.113
PostgreSQL host | localhost
PostgreSQL port | 5432
PostgreSQL database | grocery_inventory
PostgreSQL user | grocerybot
PostgreSQL password | team21
Seed employee login | 000AAA / team21
SICK PicoScan LiDAR IP | 192.168.8.150
Robot receiver IP | 192.168.8.249
Optional rosbridge URL | ws://192.168.8.249:9090

The JetKVM IP is the remote KVM management interface. It is not the ROS host IP and not the LiDAR IP. Use JetKVM to view and control the JetPack / robot-host screen. When commands in this document say localhost, they refer to the JetPack / robot host when those commands or browser checks are run inside the JetKVM-controlled desktop.

Credential warning: Do not commit real API keys. For any real deployment, change the default PostgreSQL password and the default employee password before handing the system to users.

If the Gemini assistant feature is used, create order-api-postgre/config/gemini.json with the following shape:

{
"apiKey": "...",
"model": "gemini-2.0-flash"
}

3.8 Physical Setup and Pre-Flight Inspection
1. Place GOFR on a clear, level indoor floor.
2. Make sure the robot cannot roll into people, shelves, loose wires, bags, or fragile objects during first tests.
3. Confirm the ViperX/VX300S arm is mounted securely and has clear space to move.
4. Confirm the RealSense camera is mounted near the ViperX end effector.
5. Confirm the SICK PicoScan LiDAR is mounted at the front of the robot and is not blocked by the frame, battery box, or loose wiring.
6. Confirm ultrasonic sensors are installed for the front, left, right, and rear directions.
7. Confirm the STM32 base controller is connected to the motor controllers.
8. Confirm the ESP32 ultrasonic boards are connected through the expected I2C bus.
9. Confirm the drive/actuation power branch and compute/network power branch are separated.
10. Confirm the two infrared remote switches can enable and disable the control/compute branch and the drive/actuation branch.
11. Confirm the emergency stop can stop unsafe motion.
12. Confirm all batteries are charged and mechanically secured.
13. Confirm XT60/XT30 connectors are fully seated and that no connector is partially mated.

Electrical note: Typical ultrasonic ECHO lines are 5 V, while ESP32 GPIO is 3.3 V only. Use a level shifter or voltage divider before routing an ECHO signal into an ESP32 input pin.

3.9 Chassis Hardware Assembly Procedure
Author source: Darren. The following instructions preserve the existing teammate hardware installation content while clarifying the sequence for a future maintainer.

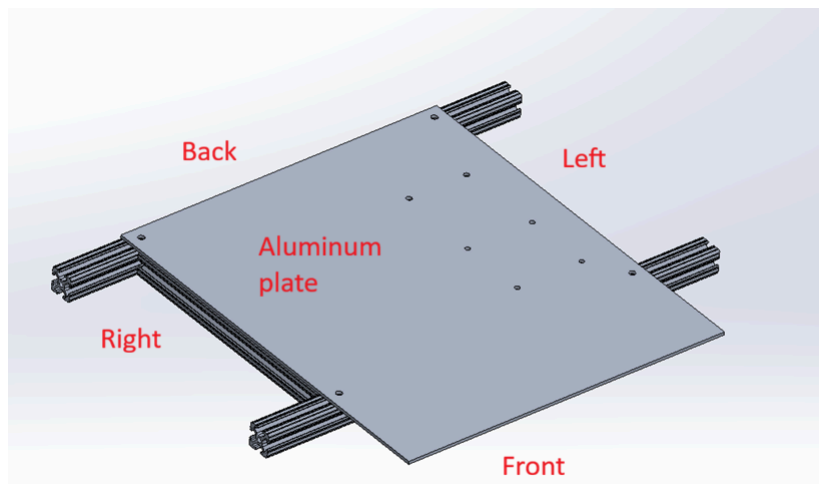
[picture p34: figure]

First-layer plate orientation

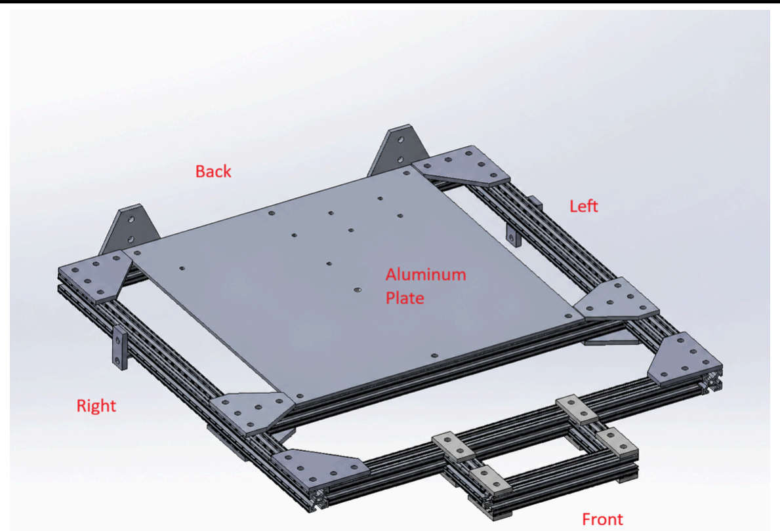
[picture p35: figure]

First-layer frame with brackets Figure 9. First-layer aluminum plate orientation and assembled lower-frame reference from the original mechanical draft.

First Layer
A partially completed first layer should be provided. Attach the M3508 holders, front and back, into the corners of the first layer using 8-32 screws and nuts placed into the 8020 slots. The front holder should face outward from the first layer. Place each M3508 motor into its holder, attach the flange to the motor with M2 screws, and attach the flange to the mecanum wheel. Make sure the mecanum wheel orientation matches the intended X-configuration so that the force vectors support omnidirectional motion. Repeat this process at all four corners.

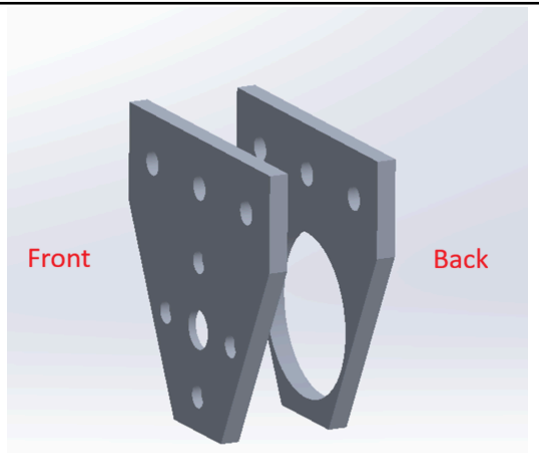
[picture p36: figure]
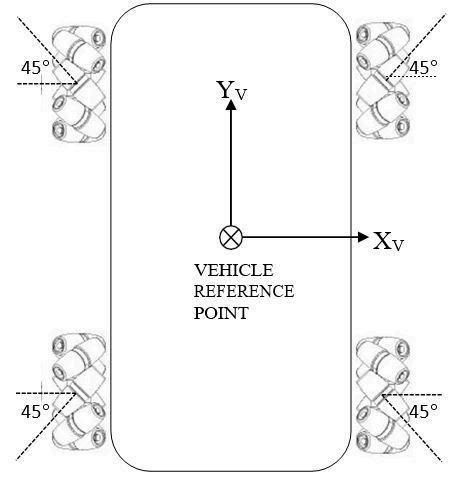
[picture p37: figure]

Mecanum wheel orientation | M3508 holder front/back CAD

Figure 10. Mecanum wheel X-configuration and M3508 motor-holder front/back reference for the four drive corners.
Place the battery holder in the front corner of the aluminum plate. The bottom of the battery holder has a hole that aligns with the bolt fixing the aluminum plate into the 8020. Place an 8020-4140 vertically and align the holes in the 4140 with the holes in the battery holder. Use 10-32 screws to fix the 4140 into the 8020 bar and battery holder. Repeat this on the left side of the aluminum plate, then attach the batteries into both holder slots.
To attach the motor driver holder, first place the four C620 controllers into the holder, with two on each side of the wall. Fix them using M2 screws and nuts. Attach the M3508 terminal board to the top of the case using M3 screws. Align the two bottom holes of the case with the two center holes in the aluminum plate, then use 10-32 screws and nuts to fix the holder in place.

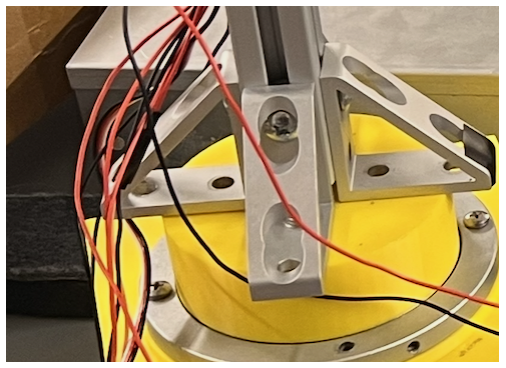
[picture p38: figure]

Battery holder / vertical-bar attachment

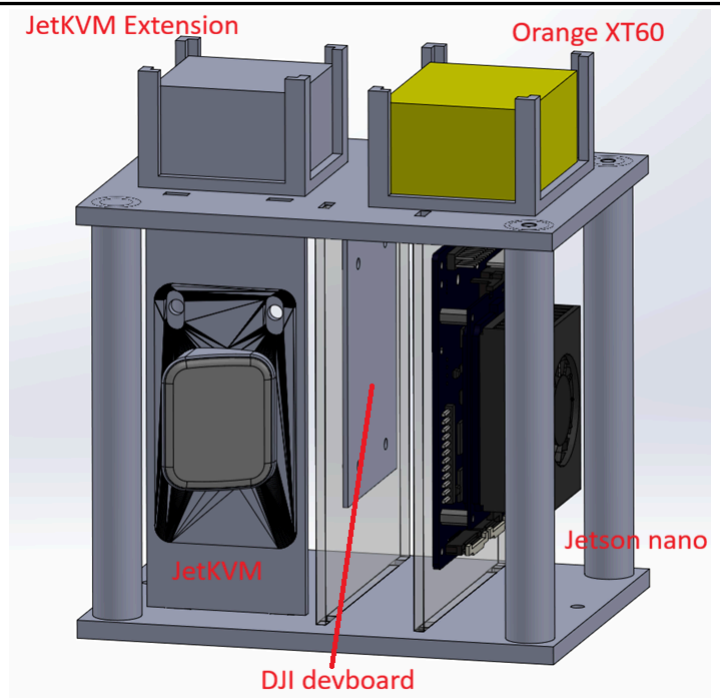
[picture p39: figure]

Cluster case electronics layout Figure 11. Battery-holder/vertical-bar attachment and cluster-case layout for JetKVM, XT60, DJI devboard, and robot computer.
The Clustercase includes a top, base, and three vertical plates. The JetKVM extension port and Orange XT60 slide into the top slots. The smallest plate holds the JetKVM with M3 screws. The second plate holds the DJI devboard with M3 screws. The final plate contains markings for attaching the Jetson Nano / robot computer. Align all vertical plate slots with the base and top parts, then attach the base to the back-right side of the aluminum plate using 10-32 screws and nuts.
Place the GL.iNet router into its holder and mount it to the back-left side of the plate. Place the LiDAR and mounting bracket at the front 8020, centered between the left and right sides of the robot. Vertically place the two 10 inch 8020-10 bars and the two 10.125 inch 8020-10 bars on the robot. The slightly longer 10.125 inch bars should be at the front side. Fix the 10.125 inch front bars with 8020-4136 and fix the two rear bars using 8020-4140. For the front vertical bars, place the front slider set into the bars. Place the right and left slider sets into both the back and front bars, and place the back sliders into the two rear bars.

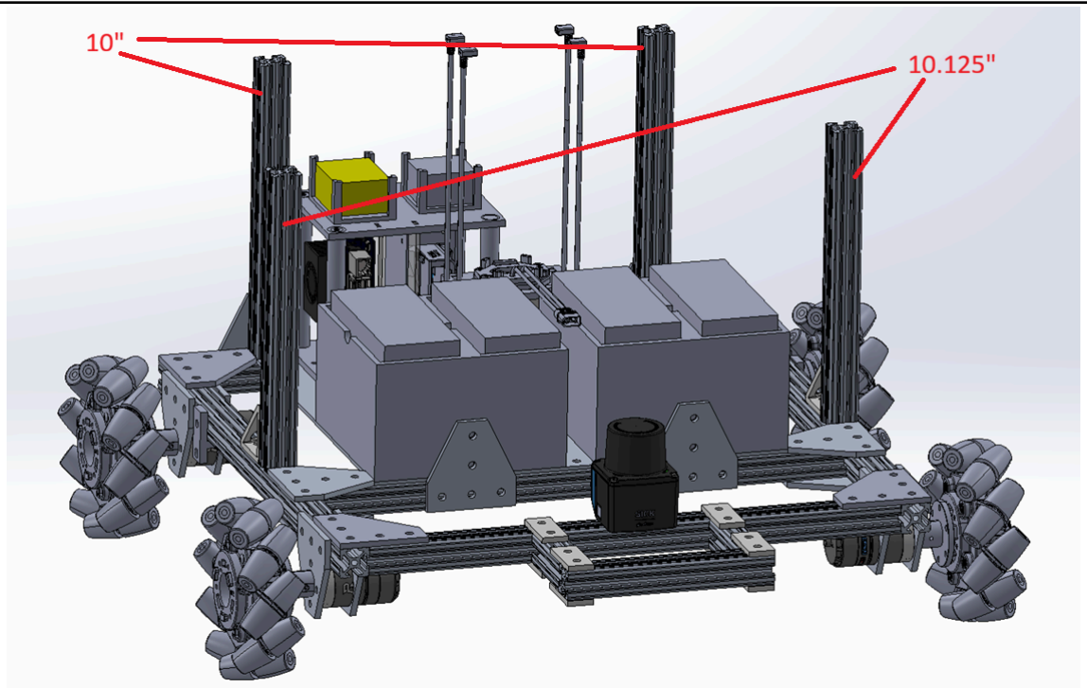
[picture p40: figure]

Vertical 8020 bar height reference Figure 12. Vertical 8020 bar placement and front/back height reference for joining the first and second chassis layers.

Second Layer
Attach the second layer to the first layer using 8020-2565 on each of the four vertical 8020 bars. Slide the 2565 into the front and back 8020 bars of the second layer, then use 8020-4151 on all four sides of the second layer. Attach four ESP32 holders to the 8020-2565. Attach the ViperX robotic arm to the top plate on the right side and place the basket on the left side. Slide four top sliders into the right and left sides of the 8020 bar.

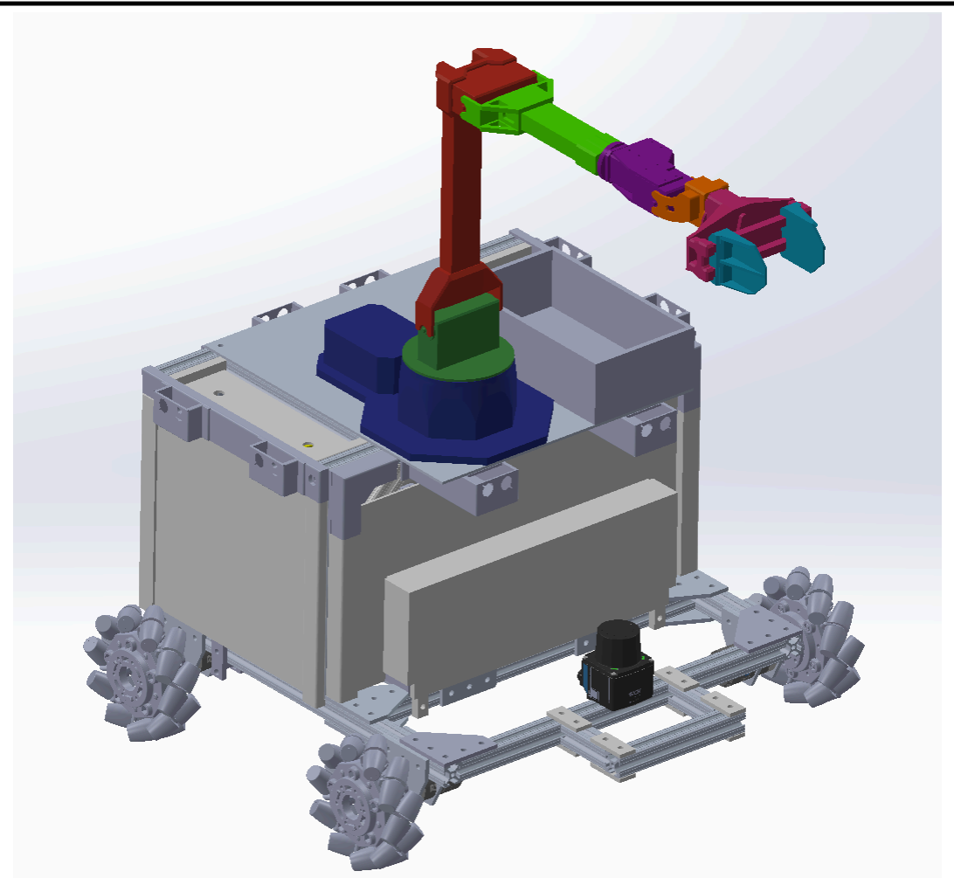
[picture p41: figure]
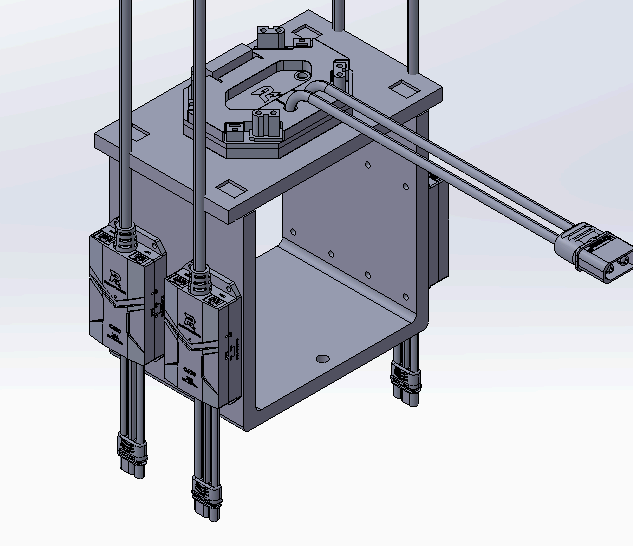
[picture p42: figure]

Second-layer structural CAD

Arm and basket placement on upper deck Figure 13. Second-layer structure and top-deck reference for arm and basket placement.

Outer Casing
Slide the 0.125 inch x 9 inch x 18.3 inch white acrylic plate into the front sliders. Place the front casing in front of the battery holders and fix it into the 8020 bar. Slide the 0.125 inch x 10.32 inch x 9 inch white acrylic plate into the right sliders. Slide the 0.125 inch x 9.3 inch x 3.1 inch white acrylic plate into the top-right sliders. Slide the right ultrasonic sensor holder into both acrylic plates and fix it into the 8020 bar using a 10-32 screw. Repeat the corresponding steps for the left side of the robot. Slide the 0.125 inch x 9.5 inch x 12.25 inch white acrylic plate into the back sliders.

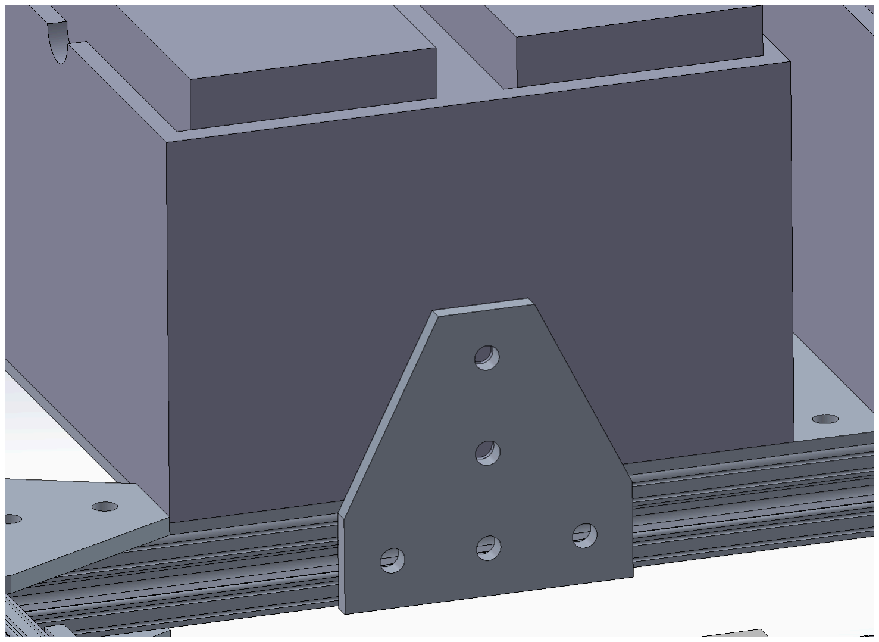
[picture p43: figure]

Acrylic/front casing detail

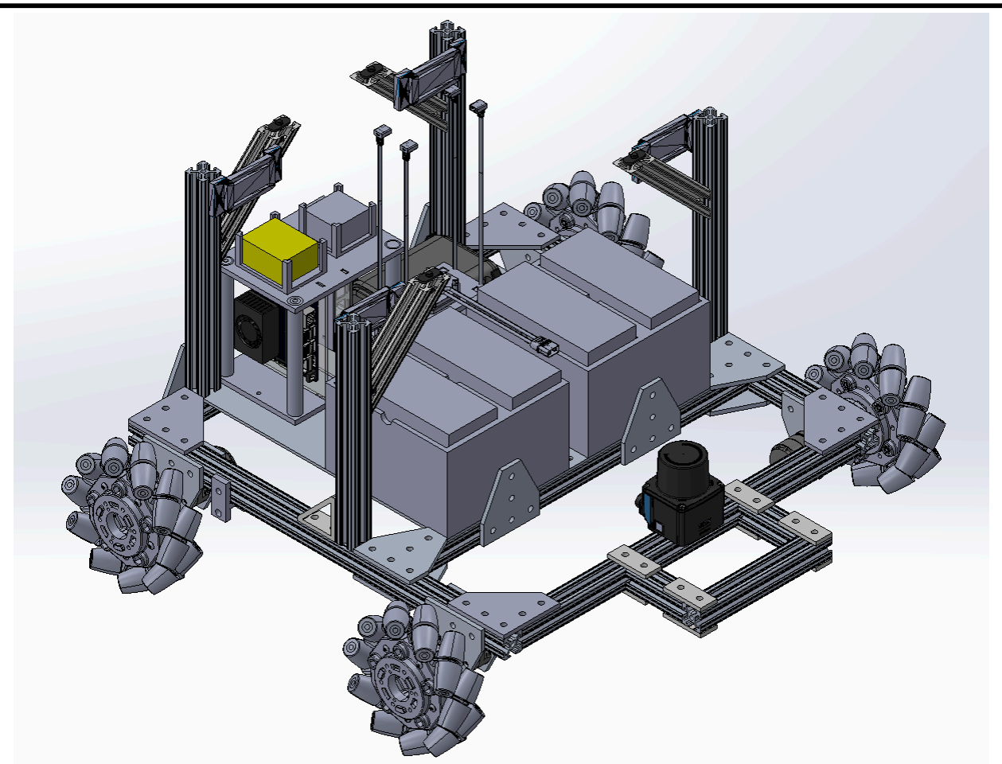
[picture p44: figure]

Full chassis CAD with outer structure Figure 14. Outer-casing reference and full chassis CAD view for final mechanical closure.

3.10 Custom Robotic Arm Prototype Assembly
Author source: Bach. This section is retained for the prototype custom-arm path. It is not the default ViperX/VX300S installation path.

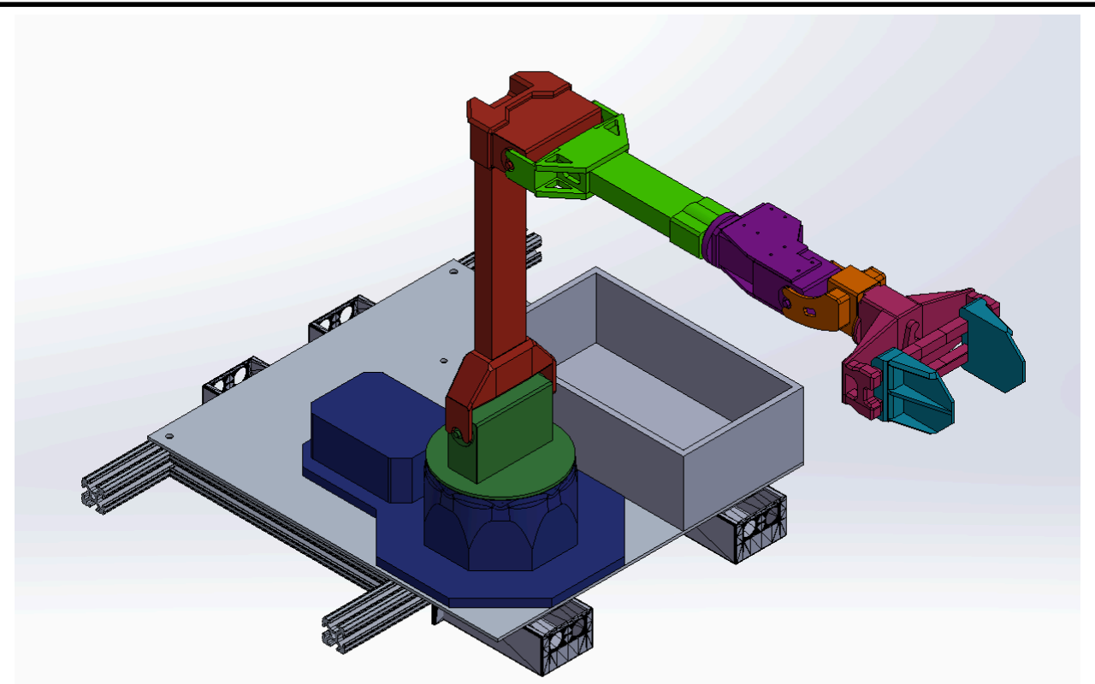
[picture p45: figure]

Custom arm mounted CAD

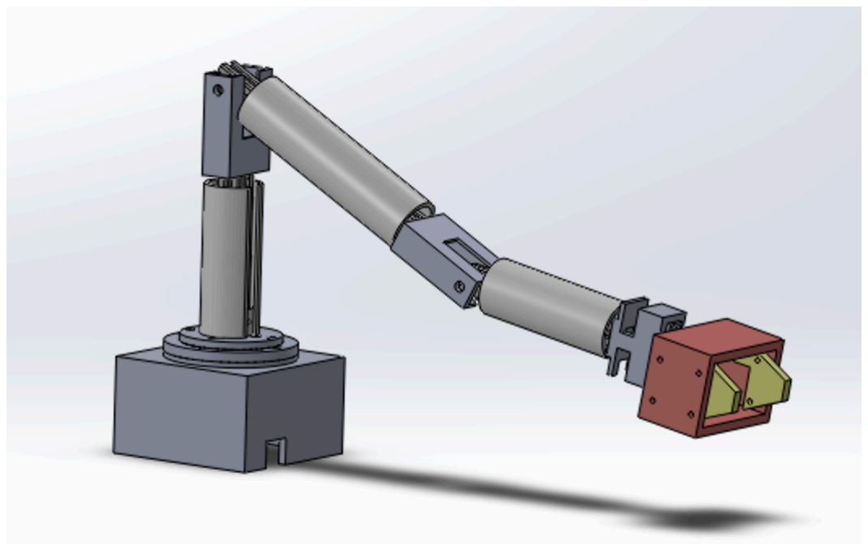
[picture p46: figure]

Custom arm standalone CAD
Figure 15. Custom robotic-arm prototype CAD references retained for the non-default prototype path.
Category | Items
8020 parts | 4x 8020 inside-corner brackets; 1x 15 cm 8020 bar; 1x 20 cm 8020 bar; 1x 25 cm 8020 bar.

Electronic components | 2x 160 kg*cm servo; 1x 80 kg*cm servo; 1x 60 kg*cm servo; 1x 30 kg*cm servo; 1x ESP32; 1x voltage reducer.
3D printed components | 1x robotic arm base; 1x gripper.
14. Attach four 8020 inside-corner brackets to one end of the 15 cm 8020 linkage using sliders and screws. Attach a 160 kg*cm servo to the other end using an M4 screw. Connect the first linkage to the base using the four bottom inside-corner bracket connections with four M4 screws.
15. Attach an 80 kg*cm servo to one end of the 25 cm linkage using an M4 screw. Connect the other end of this linkage to the motor end of the first linkage using the 160 kg*cm motor aluminum bracket.
16. Attach a 60 kg*cm servo to one end of the 20 cm 8020 linkage. Connect the other end of this linkage to the second linkage through the 80 kg*cm motor bracket. Connect the pre-assembled gripper to this linkage using the 60 kg*cm motor bracket.
17. Set up a circuit using a breadboard and 12 V supply. Connect the ESP32 to a personal computer. Connect all servo control signal wires to the ESP32 GPIO. Connect all servo grounds to the 12 V supply circuit. Connect the two 160 kg*cm servo power cables directly to 12 V. Connect the 30, 60, and 80 kg*cm servos to the voltage reducer for 6 V operation. Connect the voltage reducer power and ground to the 12 V circuit.

3.11 Embedded Firmware Setup

STM32 Base Controller
The STM32 controls the mecanum motors, receives velocity commands from ROS, and returns odometry/telemetry. Open the STM32 project and build/flash it with STM32CubeIDE or a compatible STM32 toolchain:

STM32/Base_Control_v2/robowalker2024bottominfantry-main/test/test.ioc

Parameter | Current value
MCU | STM32F427IIH6
Serial interface | USART2 at 115200 baud
CAN interface | CAN1 at 1 Mbps
Motor IDs | 0x201 through 0x204
Command frame | 0x200
Drive stack | 4x C620 + 4x M3508
Wheel radius | 0.076 m
Wheelbase | 0.36 m
Wheeltrack | 0.30 m

After flashing, connect the STM32 serial device to the robot host. The preferred Linux by-id path for the current full system is:

/dev/serial/by-id/usb-Silicon_Labs_CP2102_USB_to_UART_Bridge_Controller_0001-if00-port0

ESP32 Ultrasonic and Actuator Boards

Folder | Purpose
ESP32/ultrasonic_I2C | Ultrasonic sensor firmware used by the ROS ultrasonic collision-alert stack.
ESP32/arm_servo_I2C | Custom servo-arm I2C prototype; not the default ViperX path.
ESP32/linear_actuator | Linear-actuator prototype.
ESP32/ultrasonic | Arduino ultrasonic sketch.
ESP32/servo-component-testing | Arduino servo test sketches.

Typical ESP-IDF flashing flow:

cd ESP32/ultrasonic_I2C
idf.py set-target esp32
idf.py build
idf.py -p /dev/ttyUSB0 flash monitor
Direction | I2C address
Front | 0x09
Left | 0x10
Right | 0x11
Back | 0x12
Signal | Pin
Channel 1 TRIG | GPIO4
Channel 1 ECHO | GPIO16
Channel 2 TRIG | GPIO17
Channel 2 ECHO | GPIO34
I2C SDA | GPIO21
I2C SCL | GPIO22

3.12 Robot Host Software Setup
18. Connect the operator computer to the robot network.
19. Open http://192.168.8.113 in a browser.
20. Log in to the JetKVM system.
21. Confirm that the JetPack / robot-host display is visible.
22. Open a terminal on the JetPack desktop.
23. Run the remaining Linux, ROS, backend, mapping, and readiness-check commands from that terminal unless a step explicitly says to use another machine.
Install these prerequisites on the Linux robot host: ROS 2 Humble, Python 3, colcon, Node.js 20+, npm 10+, PostgreSQL 14+, Interbotix dependencies for the ViperX/VX300S arm, Intel RealSense SDK and Python dependencies, rosbridge_server if remote map viewing is needed, and deep-translator if inventory translation is used.

Build Interbotix Workspace

cd /home/grocerybot/Desktop/EC463_Team_21_Grocery_Robot/workspace/interbotix_ws source /opt/ros/humble/setup.bash
colcon build

Build GOFR ROS 2 Workspace

cd /home/grocerybot/Desktop/EC463_Team_21_Grocery_Robot/workspace
source /opt/ros/humble/setup.bash
source /home/grocerybot/Desktop/EC463_Team_21_Grocery_Robot/workspace/interbotix_ws/install/setup.bash colcon build --base-paths src
source install/setup.bash

Source Every ROS Terminal

cd /home/grocerybot/Desktop/EC463_Team_21_Grocery_Robot/workspace
source /opt/ros/humble/setup.bash
source /home/grocerybot/Desktop/EC463_Team_21_Grocery_Robot/workspace/interbotix_ws/install/setup.bash source /home/grocerybot/Desktop/EC463_Team_21_Grocery_Robot/workspace/install/setup.bash

3.13 Backend and Fleet UI Setup

Linux Backend Setup

sudo apt update
sudo apt install -y postgresql postgresql-contrib sudo systemctl enable --now postgresql
Create the database role and database:

sudo -u postgres psql
Inside psql, run:

CREATE ROLE grocerybot WITH LOGIN PASSWORD 'team21'; CREATE DATABASE grocery_inventory OWNER grocerybot; \q
Load schema and seed data:

cd /home/grocerybot/Desktop/EC463_Team_21_Grocery_Robot/order-api-postgre
PGPASSWORD=team21 psql -h localhost -U grocerybot -d grocery_inventory -f db/init/001_schema.sql PGPASSWORD=team21 psql -h localhost -U grocerybot -d grocery_inventory -f db/init/002_seed.sql
Install backend dependencies and start the server:

cd /home/grocerybot/Desktop/EC463_Team_21_Grocery_Robot/order-api-postgre npm install
python3 -m pip install deep-translator
export PGHOST=localhost
export PGPORT=5432
export PGDATABASE=grocery_inventory export PGUSER=grocerybot
export PGPASSWORD=team21
npm run dev
Expected backend URL: http://localhost:3000

Fleet Manager UI

cd /home/grocerybot/Desktop/EC463_Team_21_Grocery_Robot/order-api-postgre/fleet-manager npm install
npm run dev -- --host 0.0.0.0
Open the UI and log in using the seeded account:

http://localhost:5174

000AAA / team21

Windows Backend Option
For a Windows-only backend/UI test, use Docker Desktop for PostgreSQL. This path is useful for backend/UI testing, but the robot ROS stack is intended to run on the Linux robot host.

cd F:\EC463\EC463_Team_21_Grocery_Robot\order-api-postgre
docker compose up -d
npm install
npm run dev

cd F:\EC463\EC463_Team_21_Grocery_Robot\order-api-postgre\fleet-manager npm install
npm run dev

3.14 Store Map and Semantic Layout Setup
This setup is required before the frontend order workflow can drive the robot automatically. The app needs both a base navigation map and a semantic store layout so a product order such as Apple can become a navigation goal and pickup target.

Create the Base Navigation Map

cd /home/grocerybot/Desktop/EC463_Team_21_Grocery_Robot/workspace
source /opt/ros/humble/setup.bash
source /home/grocerybot/Desktop/EC463_Team_21_Grocery_Robot/workspace/interbotix_ws/install/setup.bash source /home/grocerybot/Desktop/EC463_Team_21_Grocery_Robot/workspace/install/setup.bash
ros2 run robot_navigation nav_assistant mapping-stack
Drive the robot manually through the store aisle or test area:

ros2 run robot_navigation nav_assistant teleop
Save and export the map:

ros2 run robot_navigation nav_assistant save-map --map-name testmapMain
ros2 run robot_navigation nav_assistant export-map --map-name testmapMain
This should produce Maps/testmapMain.pbstream, Maps/testmapMain.yaml, and Maps/testmapMain.pgm. For an existing demo setup, verify that these files match the physical store layout before continuing.

Open the Store Map Editor
24. Start the backend and Fleet Manager UI if they are not already running.
25. Open http://localhost:5174.
26. Log in with 000AAA / team21.
27. Open the Store Map page. It loads the base map image and the current semantic map.

Align the Semantic Store Layout
28. Confirm the base map is the correct map for the current room or store aisle.
29. Confirm the map origin and map orientation match the physical setup. If the base map is wrong, rebuild and export the map before editing semantic objects.
30. Enable Edit Mode.
31. Position the Home anchor at the robot's normal start/return location.
32. Position approach anchors near the shelf areas the robot should serve.
33. Drag each rack rectangle to the physical rack or shelf location.
34. Rotate racks or anchors when their yaw does not match the real shelf direction.
35. Position each product slot at the service location for that product.
36. Use the manual pose editor for precise x, y, z, and yaw values when dragging is not accurate enough.
37. Check that each product slot is associated with the correct product name and product ID.
Object type | Meaning
Anchor | Named pose such as Home or a rack approach point.
Rack | Physical shelf/rack footprint and orientation.
Slot | Product-specific target with nav_pose, service_pose, rack level, product ID, and product name.

Products are resolved through slots. The current semantic map includes product slots such as
Green Tea, Water, Apple, Orange, Lemon, Can, and Bag of Chips.

Save and Verify the Semantic Map
Click Save in the Store Map page. The system saves the active semantic map and records version history. The active semantic file is:

workspace/src/robot_navigation/config/semantic_map_testmapMain.yaml
- The Store Map page shows the expected anchors, racks, and slots.
- The selected object panel shows reasonable x, y, z, and yaw values.
- Product names in slots match the names used in test orders.
- The backend can still load the Store Map page after refresh.
- The ROS semantic map service is available after the navigation stack starts.
Semantic-map dependency: If the semantic map is missing or wrong, the frontend may still create an order, but the robot may navigate to the wrong place or fail semantic resolution.

3.15 Full System Startup
Start the following processes in separate terminals after the base map and semantic layout have been created or verified. Source the ROS environment in every ROS terminal.

Terminal 1: Backend

cd /home/grocerybot/Desktop/EC463_Team_21_Grocery_Robot/order-api-postgre npm run dev

Terminal 2: Fleet Manager UI

cd /home/grocerybot/Desktop/EC463_Team_21_Grocery_Robot/order-api-postgre/fleet-manager npm run dev -- --host 0.0.0.0

Terminal 3: Navigation Stack

cd /home/grocerybot/Desktop/EC463_Team_21_Grocery_Robot/workspace
source /opt/ros/humble/setup.bash
source /home/grocerybot/Desktop/EC463_Team_21_Grocery_Robot/workspace/interbotix_ws/install/setup.bash source /home/grocerybot/Desktop/EC463_Team_21_Grocery_Robot/workspace/install/setup.bash
ros2 run robot_navigation nav_assistant localization-stack \
--map-name testmapMain \
--with-nav2-rviz false \
--serial-port
/dev/serial/by-id/usb-Silicon_Labs_CP2102_USB_to_UART_Bridge_Controller_0001-if00-port0
This starts localization, Nav2, semantic map service, and the STM32 serial bridge.

Terminal 4: Optional Remote Map Bridge

sudo apt install ros-$ROS_DISTRO-rosbridge-server

cd /home/grocerybot/Desktop/EC463_Team_21_Grocery_Robot/workspace
source /opt/ros/humble/setup.bash
source /home/grocerybot/Desktop/EC463_Team_21_Grocery_Robot/workspace/interbotix_ws/install/setup.bash source /home/grocerybot/Desktop/EC463_Team_21_Grocery_Robot/workspace/install/setup.bash
ros2 launch rosbridge_server rosbridge_websocket_launch.xml
The embedded app should connect to ws://192.168.8.249:9090.

Terminal 5: ViperX Arm and /pick_viperx

cd /home/grocerybot/Desktop/EC463_Team_21_Grocery_Robot/workspace
source /opt/ros/humble/setup.bash
source /home/grocerybot/Desktop/EC463_Team_21_Grocery_Robot/workspace/interbotix_ws/install/setup.bash source /home/grocerybot/Desktop/EC463_Team_21_Grocery_Robot/workspace/install/setup.bash
ros2 launch robot_manipulation vx300_moveit.launch.py \

robot_model:=vx300s \
robot_name:=vx300s \
motor_port:=/dev/serial/by-id/usb-FTDI_USB__-__Serial_Converter_FT88YTG6-if00-port0
This provides MoveIt, ViperX controllers, and the /pick_viperx action server.

Terminal 6: Camera Vision

cd /home/grocerybot/Desktop/EC463_Team_21_Grocery_Robot/workspace
source /opt/ros/humble/setup.bash
source /home/grocerybot/Desktop/EC463_Team_21_Grocery_Robot/workspace/interbotix_ws/install/setup.bash source /home/grocerybot/Desktop/EC463_Team_21_Grocery_Robot/workspace/install/setup.bash
ros2 run robot_vision camera_vision --ros-args \
-p parent_frame:=vx300s/ee_gripper_link \
-p camera_mount_frame:=camera_mount_frame \
-p camera_optical_frame:=camera_color_optical_frame
For a live OpenCV preview, add:

-p show_live_window:=true
Camera ownership: Do not launch realsense2_camera separately for the current ViperX pickup flow. The camera_vision node owns the RealSense pipeline and publishes the camera TF frames used by the Behavior Tree and arm stack.

Terminal 7: Behavior Tree Executor

cd /home/grocerybot/Desktop/EC463_Team_21_Grocery_Robot/workspace
source /opt/ros/humble/setup.bash
source /home/grocerybot/Desktop/EC463_Team_21_Grocery_Robot/workspace/interbotix_ws/install/setup.bash
source /home/grocerybot/Desktop/EC463_Team_21_Grocery_Robot/workspace/install/setup.bash
ros2 run robot_task_manager bt_executor_viperX
Launch conflict warning: Do not launch robot_manipulation vx300_auto_pick.launch.py for the Behavior Tree full-system flow. That older launch starts vision_auto_pick.py, which can compete with bt_executor_viperX for /detections_json and /pick_viperx. The capital X in bt_executor_viperX matters.

3.16 Readiness Checks
Before giving the robot to a user, run these checks from the JetPack / robot-host terminal through JetKVM unless noted otherwise. If any check fails, stop and troubleshoot before running a
user-facing pickup task.
System | Command or check | Expected result
Remote console | Open http://192.168.8.113 from the operator computer | JetKVM shows the JetPack / robot-host screen.
Backend | Open http://localhost:3000 | Backend is listening.
UI | Open http://localhost:5174 | Login page or dashboard appears.
Customer app | Open deployed customer app URL | Order page appears.
Arm action | ros2 action list | grep pick_viperx | /pick_viperx
Navigation action | ros2 action list | grep navigate_to_pose | /navigate_to_pose
Semantic map | ros2 service list | grep semantic_map | /semantic_map/resolve_target
Camera detections | ros2 topic hz /detections_json | Topic publishes when camera is active.
One detection payload | ros2 topic echo /detections_json --once | JSON detection payload appears when target is visible.
Order service | ros2 service list | grep order | /order/new
Semantic layout | Refresh Store Map page | Correct home anchor, racks, and product slots.
Remote power controls | Test both infrared remote switches during setup | Control/compute and drive/actuation branches respond as expected.
Emergency stop | Press E-stop during a controlled test | Unsafe motion stops.
Optional rosbridge | ros2 node list | grep rosbridge | rosbridge node is present if remote map viewing is needed.

3.17 First Test Order
Use a single item for the first test. Recommended item names already used by the semantic map include Green Tea, Water, Apple, Orange, Lemon, Can, and Bag of Chips.
For a direct ROS-side integration test, call:

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

cat > /tmp/apple_order.yaml <<'EOF'
order:
order_id: 1
role: customer
requester_id: test
items:
- product_id: '3'
name: Apple
aisle: '0'
rack: 0
shelf_level: 2
qty: 1
price: 0.0
stock: 1
EOF

REQUEST="$(cat /tmp/apple_order.yaml)"
ros2 service call /order/new robot_interfaces/srv/NewOrder "$REQUEST"
Quantity constraint: Use qty: 1 for current pickup testing. The current implementation handles one physical pickup per order line; larger quantities can create a mismatch between physical pickup count and inventory decrement.

3.18 Expected Result of a Full Pickup Run
38. The backend stores the order.
39. bt_executor_viperX polls or receives the order.
40. The semantic map resolves the navigation target for the item.
41. Nav2 drives the base to the shelf stop pose.
42. The arm moves to a scan pose.
43. camera_vision publishes detections on /detections_json.
44. The Behavior Tree filters the detection and generates pregrasp, grasp, lift, and place poses.
45. /pick_viperx executes the grasp through MoveIt.
46. The item is placed into the next basket pose.
47. Inventory is updated through the backend.
48. The order is marked done or failed.
Current basket placement is sequential. The first picked object goes to basket slot 1, the second to basket slot 2, and so on. Basket placement is not yet type-aware.

3.19 Software Updates After a New Release
49. Pull or copy the new repository version onto the robot host.
50. Read release notes or team handoff notes for changed packages.
51. Rebuild affected ROS packages. For full integration changes, use the command below.

cd /home/grocerybot/Desktop/EC463_Team_21_Grocery_Robot/workspace
source /opt/ros/humble/setup.bash
source /home/grocerybot/Desktop/EC463_Team_21_Grocery_Robot/workspace/interbotix_ws/install/setup.bash colcon build --base-paths src --packages-select \
robot_interfaces robot_navigation robot_manipulation robot_vision robot_task_manager
source install/setup.bash
If backend dependencies changed:

cd /home/grocerybot/Desktop/EC463_Team_21_Grocery_Robot/order-api-postgre npm install
If Fleet UI dependencies changed:

cd /home/grocerybot/Desktop/EC463_Team_21_Grocery_Robot/order-api-postgre/fleet-manager
npm install
- If database schema changed, back up the database before running migrations or reloading seed data.
- If embedded firmware changed, reflash the matching STM32 or ESP32 target before running the full stack.
- Repeat all readiness checks before autonomous or user-facing operation.

3.20 Known Installation Boundaries
- The ViperX/VX300S path is the current primary validated path.
- The custom servo arm and rack path is not the default full-system deployment path.
- The robot status page in the UI may contain placeholder behavior and should not be treated as complete live telemetry unless updated.
- The SLAM web page requires rosbridge_server and the correct robot host/IP.
- Shelf-level semantic poses are resolved in the current customer pickup path, but shelf-level arm pose execution is not fully connected in the current customer tree.
- The current customer pickup flow is fail-fast. It does not yet support per-item skip, partial-success settlement, or continue-after-failure behavior.
- Return-home recovery has a retry budget, but a recovered return home still preserves the order result as failed if the original order failed.

3.21 Setup Completion Checklist
- [ ] The robot powers on without loose wiring, battery, or connector issues.
- [ ] The two infrared remote switches can control the control/compute and drive/actuation power branches.
- [ ] The emergency stop can stop unsafe motion.
- [ ] JetKVM at http://192.168.8.113 can access the JetPack / robot-host desktop.
- [ ] The backend and UI are reachable.
- [ ] The customer app and Fleet Manager are reachable for daily users.
- [ ] The base map has been created or verified for the current location.
- [ ] The Store Map semantic layout has been saved with the correct home anchor, racks, and product slots.
- [ ] The navigation action is available.
- [ ] The semantic map service is available.
- [ ] The arm action server is available.
- [ ] The camera publishes detections.
- [ ] A one-item test order can be accepted by the Behavior Tree.

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
## 4. User's Manual

Author source: Lion (Xingjian Jiang). This section describes how to use and operate GOFR after the setup and installation process has been completed. It assumes the base map, semantic store layout, backend, Fleet Manager UI, customer app, robot host, navigation stack, camera stack, arm stack, and Behavior Tree executor have already been brought up by a maintainer. It also assumes that the installer will walk the client through these procedures during customer installation.

4.1 User Roles

Role | Main interface | Main responsibility
Customer or demo user | Customer app | Submit a pickup request and monitor order progress.
Store employee / operator | Fleet Manager UI and physical safety controls | Monitor robot readiness, store map, inventory, and task progress.
Maintainer / integration operator | JetKVM remote console, Fleet Manager, physical controls | Recover from abnormal states, restart services, and run diagnostic checks.

Daily users should use the customer app and Fleet Manager UI. Command-line access is reserved for setup, maintenance, and recovery.

4.2 Before Operation
Before starting a pickup run, the store employee or maintainer should confirm:
- The robot is in the mapped store/test area.
- The aisle and arm workspace are clear of people, loose cables, bags, and fragile objects.
- The two infrared remote power switches are available and working.
- The emergency stop is reachable.
- The customer app is reachable.
- The Fleet Manager UI is reachable.
- The Store Map page shows the correct home anchor, racks, and product slots.
- The robot has already passed the setup readiness checks.
Do not start a pickup task: Do not start a pickup task if the map is wrong, the robot is outside the mapped area, the camera is blocked, or the emergency stop is not reachable.

4.3 Operating Mode 1: Customer Pickup

Purpose
Customer Pickup mode lets a customer or demo user request grocery items from the customer app. The robot uses the saved semantic store map to navigate to the product area, detect the target object, pick it with the ViperX arm, place it in the basket area, and update order progress.

User Interface
The customer uses the customer app. The exact deployment URL is deployment-specific and should be recorded during installation handoff. The customer app should provide product browsing or item selection, order submission, and order status/progress display.

Normal Operation
52. Open the customer app.
53. Select the desired product.
54. For the current prototype, use one item per order line and set quantity to 1.
55. Submit the order.
56. Wait for the app or operator to show that the order has been received.
57. Keep clear of the robot path and arm workspace while the robot is moving.
58. When the robot finishes, retrieve the item only after the robot has stopped moving.
The expected robot response is: backend records the order; task manager accepts it; semantic map resolves the product into a navigation target; mobile base navigates to the product area; ViperX moves to a scan pose; RealSense and vision stack search for the object; the arm picks the item and places it into the basket; backend updates inventory and order state; robot returns home after success or attempts failure recovery if the order fails before completion.

Abnormal Results and Recovery

Abnormal result | What the user may see | Recovery
Product name does not match the semantic map | Order does not execute or fails quickly | Store employee checks product name and slot assignment in Fleet Manager.
Robot cannot navigate to the target | Robot stops or reports failure | Store employee clears obstacles; maintainer checks navigation and semantic map.
Camera cannot detect the item | Robot scans but does not pick | Store employee checks object visibility and lighting; maintainer checks /detections_json.
Arm cannot pick the object | Robot may report failed order | Store employee keeps area clear; maintainer runs arm/camera diagnostics.
Quantity is greater than 1 | Inventory may not match physical pickup count | Use qty: 1 per order line until this feature is updated.
Robot returns home after failure | Order remains failed even if robot reaches home | This is expected failure-recovery behavior.

Exit or Stop
The customer should not physically stop the robot unless there is immediate danger. If the robot is operating unsafely, press the emergency stop or ask the store employee to press it, keep clear of the robot, and wait for the store employee or maintainer to recover the system.

This feature not yet implemented: Customer-side order cancellation from the app is not documented as a reliable active stop mechanism for the current robot. Use the store employee safety procedure for stopping active robot motion.

4.4 Operating Mode 2: Store Employee / Fleet Manager Operation

Purpose
Store Employee mode is used by a store employee or demo operator to monitor robot readiness, view inventory, inspect the semantic store map, and observe task progress. This role should not require command-line access during normal operation.

User Interface
Open the Fleet Manager UI at http://localhost:5174 when viewing from the JetKVM-controlled robot host. If viewing from another laptop, use the deployed network address for the Fleet Manager server. Log in with 000AAA / team21 for first bring-up, and replace the password for real deployment.

Normal Operation
59. Open Fleet Manager.
60. Log in as an employee.
61. Open the dashboard or robot status page.
62. Confirm the robot is ready for a task.
63. Open the Store Map page.
64. Confirm the home anchor, racks, and product slots match the physical store layout.
65. Open the inventory page and confirm the target product is present.
66. Watch the customer app or backend order status while the robot executes the order.
67. Keep the aisle clear and monitor the emergency stop.
The expected system response is that Fleet Manager loads inventory and semantic map data from the backend, Store Map displays anchors/racks/slots on top of the saved map, backend receives and tracks orders, and robot_task_manager consumes pending orders when the ROS stack is running.

Store Map Viewing
Use the Store Map page to verify that the semantic layout is still correct. During normal operation, do not move anchors, racks, or slots unless the physical store layout has changed. If a rack or product has been moved, pause operation, enable edit mode, move the affected semantic object, save the semantic map, ask the maintainer to verify the semantic map service if needed, and run a one-item test before returning to customer operation.

Inventory Viewing
Use the inventory page to check product names and stock values. Product names should match semantic map product slot names. Current test product names include Green Tea, Water, Apple, Orange, Lemon, Can, and Bag of Chips.

Abnormal Results and Recovery

Abnormal result | Store employee action
Fleet Manager cannot load | Ask maintainer to check backend and UI services.
Store Map is wrong | Stop operation; correct and save semantic map before running pickup.
Product is missing from inventory | Update inventory or use a valid product.
Robot status page does not match physical robot | Treat physical robot and maintainer checks as authoritative.
Robot moves toward an obstacle | Press emergency stop.
Order fails | Keep the area clear; ask maintainer to check backend, navigation, vision, and arm status.

This feature not yet implemented: The robot status page may contain placeholder or incomplete live telemetry depending on the current software version. Do not rely on it as the only safety indicator.

Exit or Stop
To stop normal monitoring, log out of Fleet Manager or close the browser tab. To stop active robot operation, press the emergency stop if there is immediate danger, use the infrared remote switch to disable the relevant power branch when instructed by the maintainer, keep people away from the robot until it is confirmed safe, and do not restart an order until the abnormal state has been cleared.

4.5 Operating Mode 3: Maintainer Diagnostics and Recovery

Purpose
Maintainer mode is used only when the robot must be checked, restarted, recovered, or debugged. This mode uses JetKVM and may use command-line tools. It is not a daily customer or store employee workflow.

User Interface
Use any maintenance laptop connected to the robot network and open http://192.168.8.113. This opens JetKVM, which controls the JetPack / robot-host desktop and terminal. When commands are run from this desktop, localhost refers to the JetPack / robot host.

Diagnostic Checks

System | Check
Backend | Open http://localhost:3000
Fleet Manager | Open http://localhost:5174
Arm action | ros2 action list | grep pick_viperx
Navigation action | ros2 action list | grep navigate_to_pose
Semantic map service | ros2 service list | grep semantic_map
Camera detections | ros2 topic hz /detections_json
Order service | ros2 service list | grep order
Optional remote map bridge | ros2 node list | grep rosbridge

Recovery Procedure
68. Stop unsafe motion with the emergency stop if needed.
69. Keep the aisle and arm workspace clear.
70. Record what mode the robot was in: navigation, scan, pick, basket place, return home, or idle.
71. Check whether the backend and Fleet Manager are still reachable.
72. Check whether /navigate_to_pose, /pick_viperx, /detections_json, and /semantic_map/resolve_target are available.
73. Confirm the semantic map still matches the physical rack/product layout.
74. Confirm the target object is visible to the camera.
75. Reset or restart only the failed subsystem when possible.
76. Run a one-item test order with qty: 1.
77. Return the robot to customer operation only after the test passes.

Built-In Recovery Behavior
The current customer pickup tree has return-home recovery. If a customer order fails before all items are complete, the robot attempts to navigate back to the configured home_goal. The order remains marked as failed even if the robot successfully returns home. This behavior is intentional because a failed pickup should not be reported as successful just because the robot recovered its position.

This feature not yet implemented: GOFR does not currently provide a single in-app self-test button that verifies backend, navigation, arm, camera, semantic map, and safety controls together. For now, maintainers use the readiness checks in this manual as the diagnostic mode.

4.6 Operating Mode 4: Store Map Adjustment

Purpose
Store Map Adjustment mode is used when the physical store layout changes. It should be performed by a store employee with maintainer support or by the maintainer directly.

User Interface
Use Fleet Manager at http://localhost:5174 and open the Store Map page.

Normal Operation
78. Stop active robot tasks.
79. Open Store Map.
80. Confirm the base map still matches the physical space.
81. Enable edit mode.
82. Move the home anchor if the robot start location changed.
83. Move approach anchors if the robot should approach shelves from a different location.
84. Move or rotate racks if shelves moved.
85. Move product slots if product locations changed.
86. Save the semantic map.
87. Run a one-item pickup test before allowing customer use.
The expected system response is that the UI saves the active semantic map, the backend records semantic map version history, and the ROS semantic map server can resolve future orders against the updated semantic map.

Abnormal Results and Recovery

Abnormal result | Recovery
Base map is wrong | Rebuild and export the navigation map before editing semantic objects.
Product slot does not match inventory name | Correct product name or product ID before running pickup.
Robot navigates to the wrong side of a rack | Adjust slot nav_pose, rack yaw, or approach anchor.
Robot stops too far from the product | Ask maintainer to verify semantic pose and Nav2 local costmap behavior.

This feature not yet implemented: Shelf-level semantic service_pose is not fully connected to the current customer pickup arm execution path. The current system uses semantic targets mainly for navigation and product/rack context.

4.7 Operating Mode 5: Emergency Stop and Power Control

Purpose
Emergency Stop and Power Control mode is used to stop unsafe motion or to disable parts of the robot during setup and recovery.
Control | Use
Emergency stop | Stop unsafe robot motion immediately.
Infrared remote switch for control/compute branch | Enable or disable control/compute power during setup or recovery.
Infrared remote switch for drive/actuation branch | Enable or disable drive/actuation power during setup or recovery.

Normal Stop Procedure
88. Wait until the robot is idle.
89. Close or log out of customer app and Fleet Manager sessions.
90. Ask the maintainer to stop running ROS/backend processes.
91. Use the infrared remote switches to disable power branches as appropriate.
92. Confirm the robot is no longer moving.

Emergency Stop Procedure
93. Press the emergency stop.
94. Do not stand in the robot path or arm workspace.
95. Tell the maintainer what happened.
96. Do not release or reset the robot until the maintainer confirms the cause.
97. After recovery, run readiness checks before the next order.

4.8 Operating Limits and Not-Yet-Implemented Features
- Use one physical pickup per order line. Current pickup tests should use qty: 1.
- Basket placement is sequential, not item-type-aware.
- Customer-side cancellation is not documented as a reliable active stop mechanism.
- Partial-success order settlement is not implemented.
- Full shelf-level arm motion driven directly by semantic service_pose is not yet implemented in the customer pickup tree.
- A single in-app self-test button is not implemented.
- Multi-robot fleet operation is future work.
- The robot status page may not contain complete live telemetry in the current software version. These limits should be reviewed with the client during installation handoff.

4.9 Where to Get Help
98. Stop unsafe motion first.
99. Record the operating mode, item name, and visible error.
100. Check Fleet Manager and the customer app for order state.
101. Ask the maintainer to inspect JetKVM and ROS diagnostics.
102. Use the troubleshooting section of the full documentation for subsystem-specific recovery. For course or project maintenance, contact the GOFR team member assigned to the affected subsystem.

## 5. Safety Issues

Author source: Pree for general robot and data/software safety; Darren for water-exposure hazard; Bach for custom-arm startup hazard; Lion for final consolidation.

5.1 General Robot Safety
- GOFR has moving wheels, an articulated robotic arm, batteries, and active sensing hardware.
- Keep operators and bystanders clear of the arm workspace before enabling motion.
- Ensure the remote E-stop is accessible during every run.
- Do not place hands inside the arm or wheel path while the robot is active.
- Do not operate with loose wiring, unstable battery connections, or exposed power terminals.
- Use SLAM and robot-status pages as supervisory tools only; they are not substitutes for direct human safety observation.

5.2 Data and Software Safety
- Employee pages require authentication.
- Database credentials are currently simple development credentials and should be changed for deployment outside a lab environment.
- API keys stored in config/gemini.json must not be committed to public repositories.

5.3 Recovery Guidance for Common Abnormal States
- If the robot behaves unpredictably, activate the physical E-stop first and investigate software second.
- If localization drifts or the robot no longer tracks the map correctly, stop navigation, relaunch localization, and verify the active map files.
- If the arm stalls or cannot complete a pick, stop the arm action, verify the USB connection and MoveIt bring-up, then retest with a preview or diagnostic launch.
- If the UI becomes unresponsive while ROS is still running, do not assume the robot is safe; use the E-stop or terminate motion nodes directly.

5.4 Water and Custom-Arm Hazards
- Darren: Keep the robot away from water sources because holes in the casing could allow water to leak into the system.
- Bach: Maintain a sufficient distance away from the custom robotic arm during startup because the motors can move quickly while returning to their initial position.

## Appendix A: Glossary

The following terms should remain consistent across the installation section, user manual, safety section, and troubleshooting section.

Term | Definition
GOFR | Grocery Operations and Fulfillment Robot; the mobile manipulator developed by Team 21.
ROS 2 | Robot Operating System 2; middleware used for robot nodes, topics, services, actions, and launch processes.
Behavior Tree | The task-execution structure used by GOFR to sequence order handling, navigation, perception, picking, placement, and recovery.
Nav2 | ROS 2 navigation framework used for localization-to-goal driving and navigation actions.
Cartographer | SLAM system used to build and localize against 2D maps.

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
p la

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
s, racks, slots, navigation poses, and service poses. Service pose | A pose near a shelf or product slot where the robot or arm can perform a service action such as scanning or pickup. ViperX/VX300S | The Interbotix robotic arm used as the primary validated manipulation platform. MoveIt | Motion planning framework used to command the ViperX arm and execute pick trajectories. RealSense | Intel depth camera used for visual perception and product detection. PicoScan LiDAR | SICK 2D LiDAR sensor used for mapping, localization, and navigation. STM32 | Microcontroller used for the mobile-base controller and odometry/telemetry bridge. ESP32 | Microcontroller used for ultrasonic sensor boards and prototype actuator-side firmware. Emergency stop | Hardware stop control intended to stop unsafe motion by cutting or disabling the drive/actuation branch. Infrared remote switch | Remote power switch used to enable or disable the compute/control or drive/actuation power branch. JetKVM | Remote KVM device used to access the JetPack / robot-host desktop and terminal. JetPack / robot host | The Linux computer that runs ROS, backend services, vision, navigation, and task-management processes. /pick_viperx | ROS action server used to request ViperX pick execution. /detections_json | ROS topic published by the camera vision node with object-detection payloads. /navigate_to_pose | ROS action used by Nav2 to send the mobile base to a navigation goal. /order/new | ROS service used to submit an order directly to the Behavior Tree task manager. Fleet Manager | Operator web UI used for inventory/map views, Store Map editing, and task monitoring. Customer app | Customer-facing web interface used to browse products and submit pickup requests. PostgreSQL | Relational database used by the backend for inventory, order, user, and map-related data. rosbridge | WebSocket bridge that allows web clients to communicate with ROS topics/services/actions.

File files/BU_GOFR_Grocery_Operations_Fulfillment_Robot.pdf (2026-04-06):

### SI C K $10K C hal lenge 2025 -26

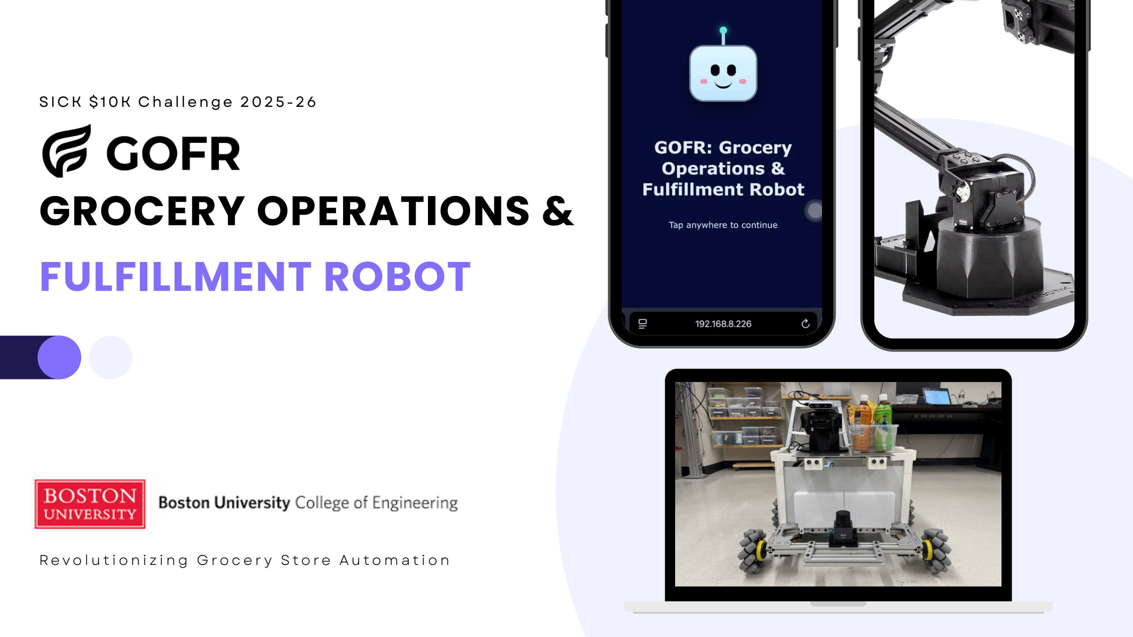
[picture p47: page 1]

# GROCERY OPERATIONS & FULFILLMENT ROBOT

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

# MEET OUR TEAM

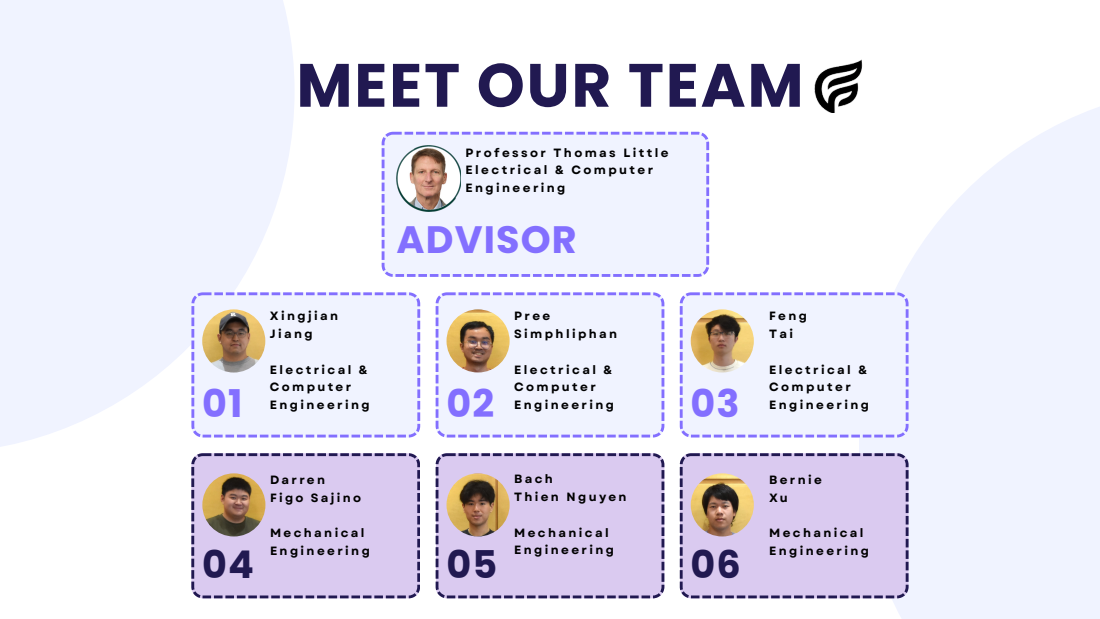
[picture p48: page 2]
ADVISOR

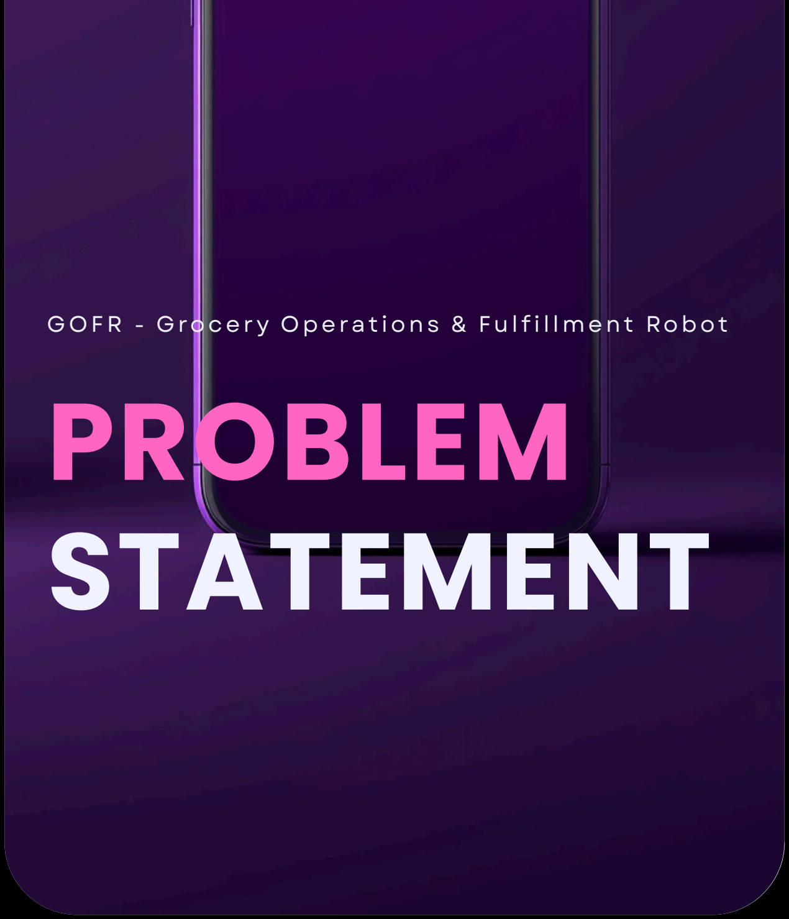
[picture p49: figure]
PROBLEM STATEMENT

G O FR - G rocer y O perat ions & Ful f i l lment Robot

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

## Severe la b or shor tages

## Inef f icient manual restocking p roces ses

## R i s ing o p erat ional an d staf f ing cost s

## G rowing customer d eman d for online ord er ing

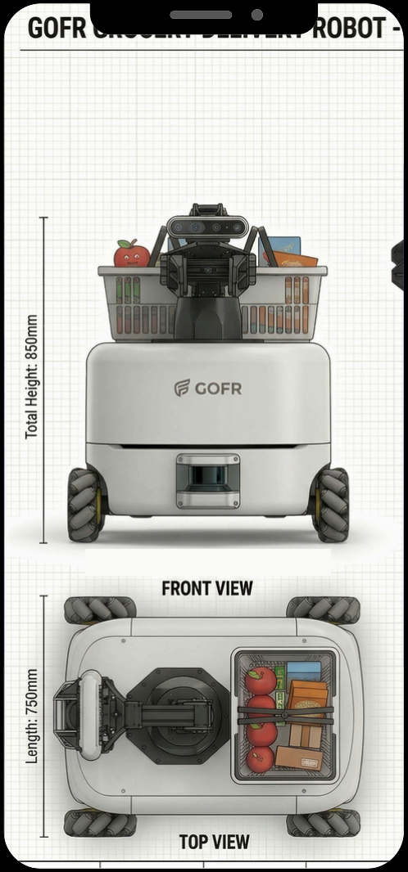
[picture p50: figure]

# PROPOSED SOLUTION

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

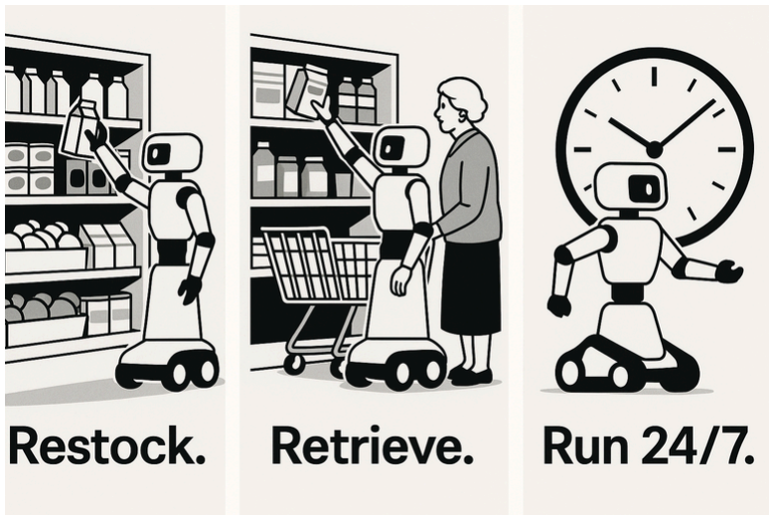
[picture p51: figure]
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

## Autonomous Ro b ot Solut ion

## Store Manager A p p Integrat ion

## C ustomer A p p

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

## 24/ 7 O p erat ions

# PROJECT PLAN

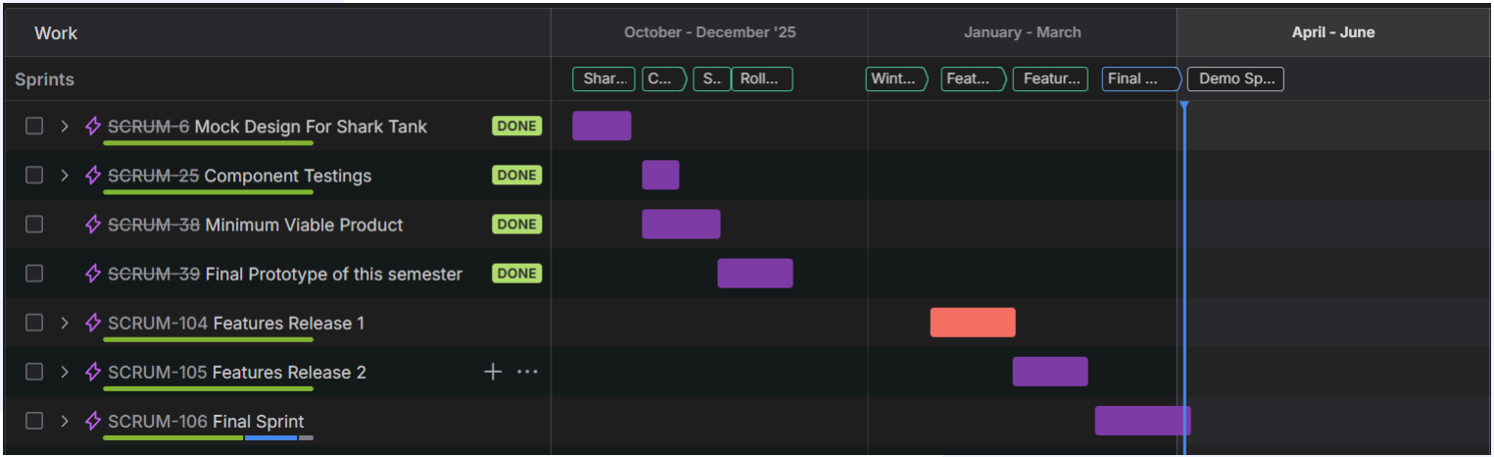
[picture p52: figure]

# ROBOT PROTOTYPE

## Intel Real sense

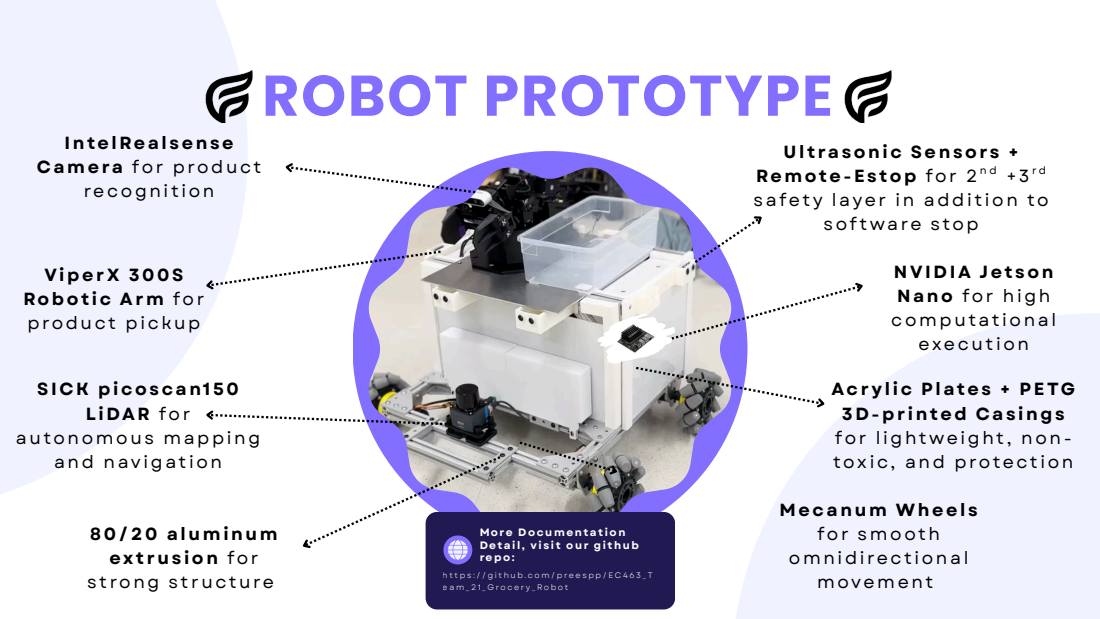
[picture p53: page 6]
SI C K p icoscan15 0 L iDA R for; Remote-Esto p for 2

U l t rasonic Sensors +
safety layer in addi t ion to

C amera for product
recogni t ion

sof tware stop

Ro b ot ic A rm for
product pickup

NV IDI A Jet son
Nano for high
computat ional
execut ion

Acrylic Plates + PETG
3D- p r inte d C as ings
for l ightweight , non-
tox ic, and protect ion

autonomous mapping
and nav igat ion

Mecanum Wheel s
for smooth
omnidi rect ional
movement

8 0 /2 0 aluminum
ext rus ion for
st rong st ructure

More Documentat ion

Detail, vi s i t our gi thu b

# CORE TECHNOLOGY

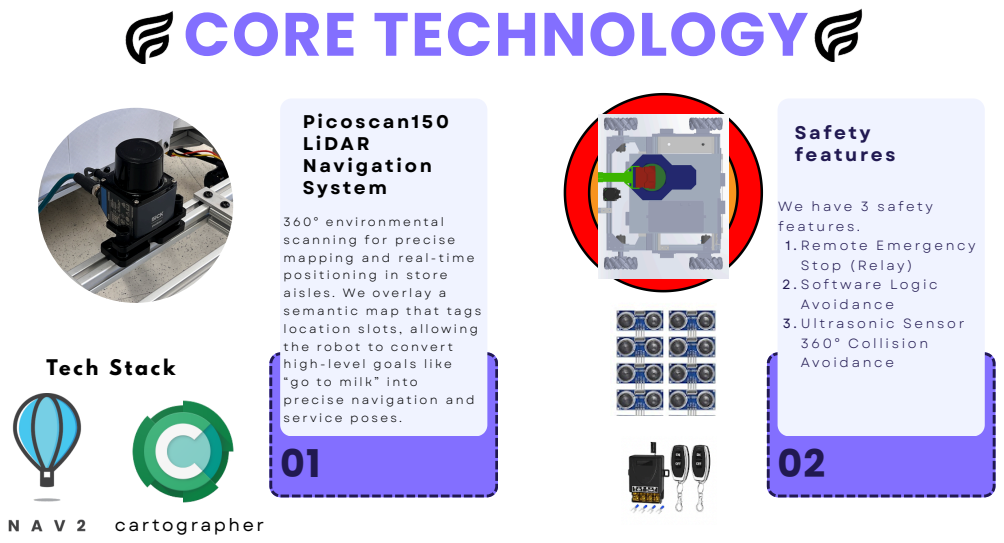
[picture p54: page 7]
Safety features; Picoscan15 0 L iDA R Navigat ion System; car tographer; Tech Stack

# CORE TECHNOLOGY

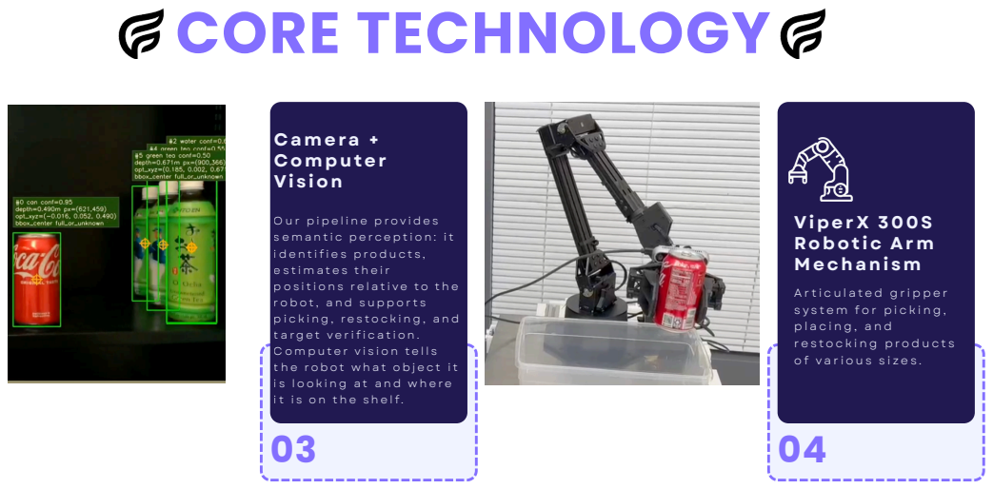
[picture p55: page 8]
C amera + C omp uter Vi s ion

Mechani sm

# 05 STORE MANAGER APP

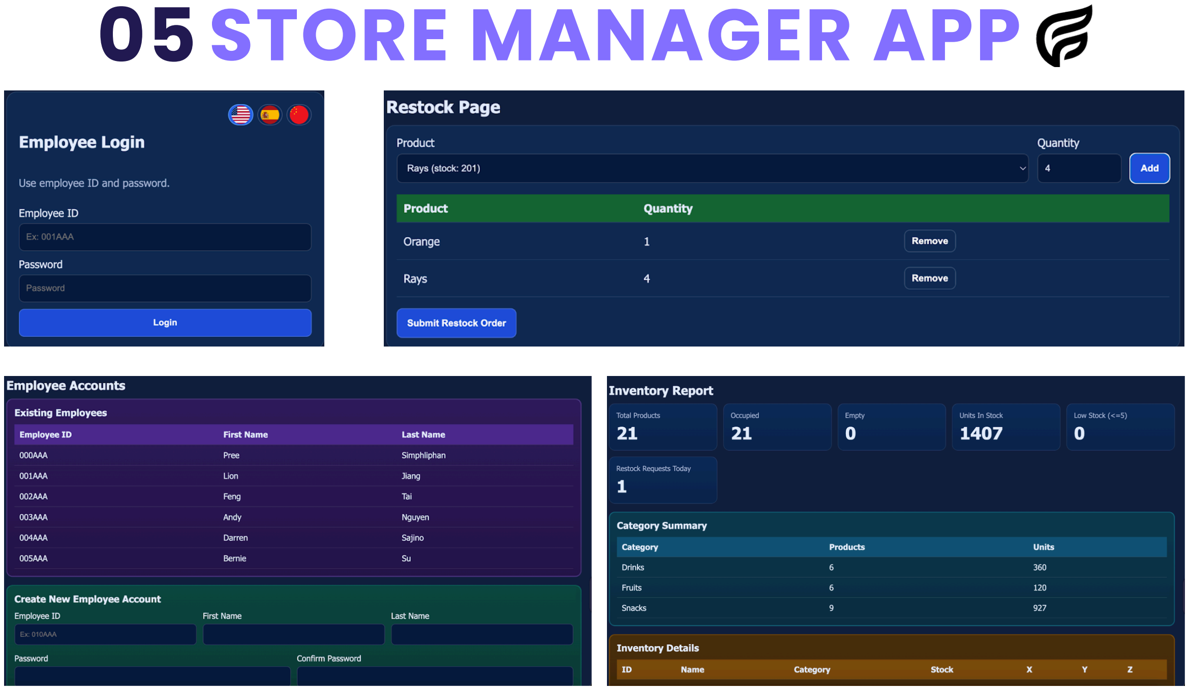
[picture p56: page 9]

# 05 STORE MANAGER APP

## Features

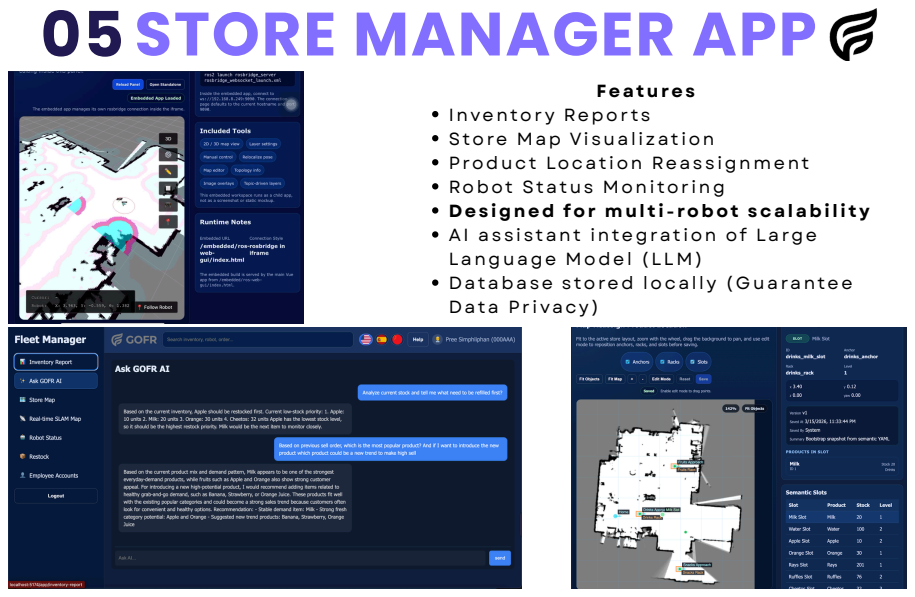
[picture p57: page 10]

Inventor y Repor t s
Store Map Vi sual i zat ion
Product Locat ion Reas s ignment
Robot Status Moni tor ing
Des igne d for mul t i - ro b ot scala b ili ty
AI as s i stant integrat ion of Large
Language Model ( L LM)
Database stored local l y ( G uarantee
Data Pr i vacy)

# 06 ONLINE ORDER APP

## Features :

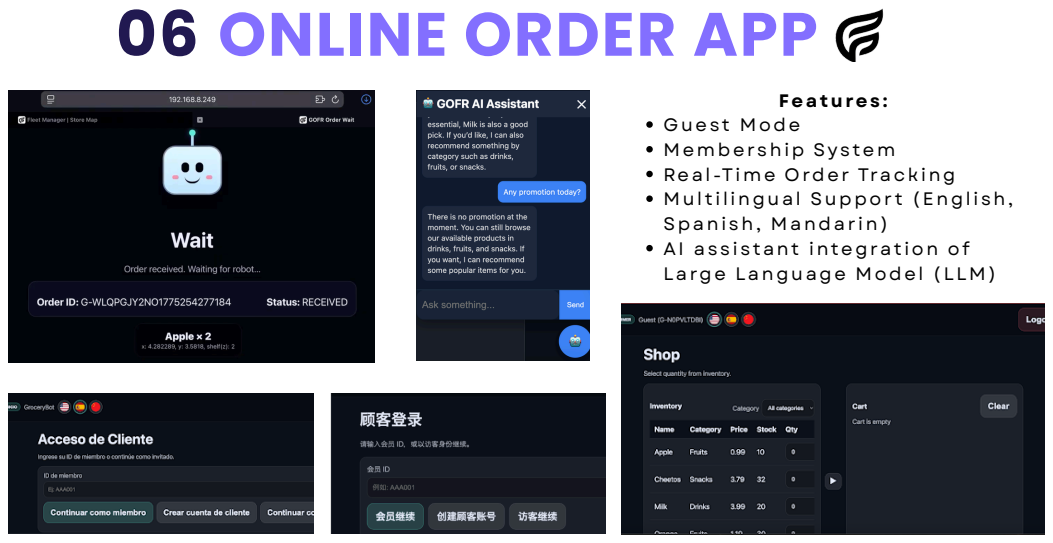
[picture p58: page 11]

G uest Mode
Membership System
Real -Time O rder Track ing
Mul t i l ingual Suppor t (Engl i sh,
Spani sh, Mandar in)
AI as s i stant integrat ion of
Large Language Model ( L LM)

# 07 SYSTEM ARCHITECTURE

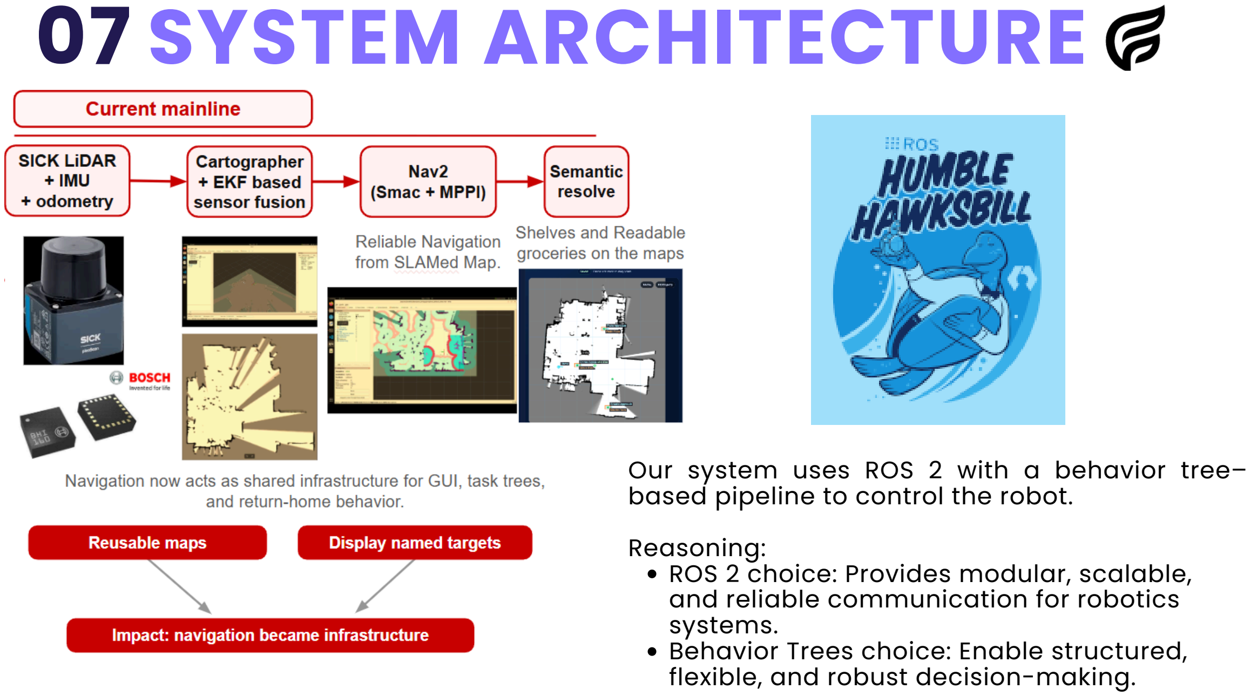
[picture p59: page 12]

# Our system uses ROS 2 with a behavior tree–

based pipeline to control the robot.

# Reasoning:

ROS 2 choice: Provides modular, scalable,

# and reliable communication for robotics

systems.
Behavior Trees choice: Enable structured, flexible, and robust decision-making.

# REAL-WORLD TESTING AND DEPLOYMENT

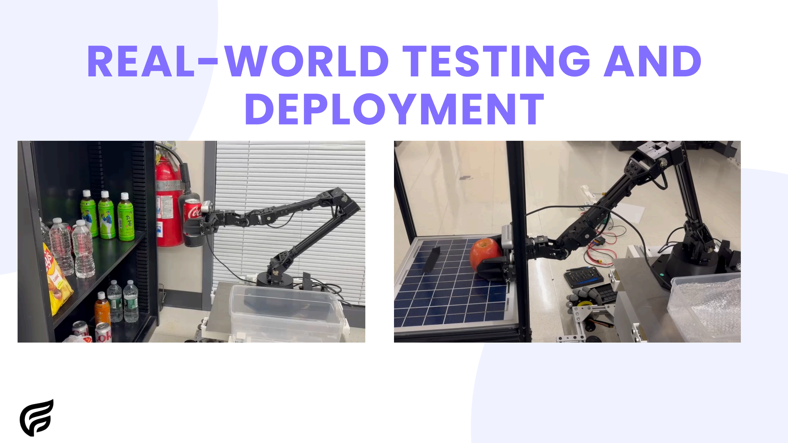
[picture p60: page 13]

# MARKET ANALYSIS

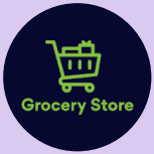
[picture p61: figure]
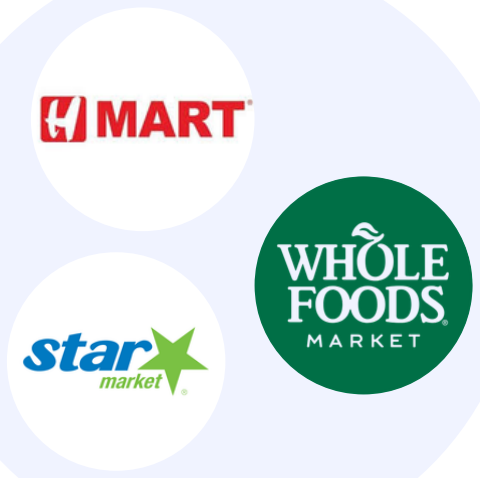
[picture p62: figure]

## 1. Local G rocer y Stores : Af fordable

robot ic | solut ions | that | f i t | t ight

## spaces and l imi ted staf f. Suppor t

inventor y management , restock ing, order ful f i l lment , store nav igat ion, and customer as s i stance.
2. Large | Supermar ket s : | Focus | on

## scalabi l i ty, speed, and integrat ion w i th ex i st ing systems to handle heav y customer t raf f ic and complex

operat ions.

## 3. O nl ine Del i ver y Plat forms : Digi tal -f i rst grocer y ser v ices w here orders are placed v ia apps and ful f i l led before del i ver y personnel s ar r i ve for faster turnaround t imes

# Key Sector target

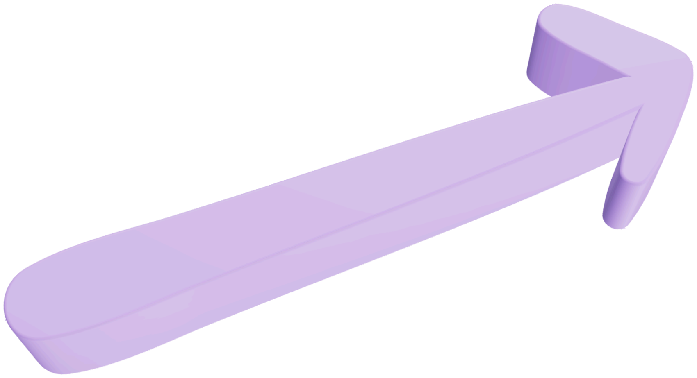
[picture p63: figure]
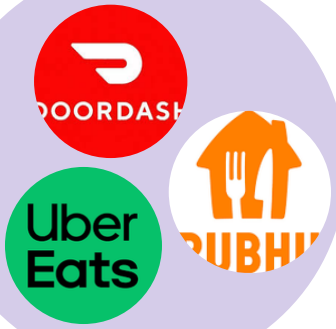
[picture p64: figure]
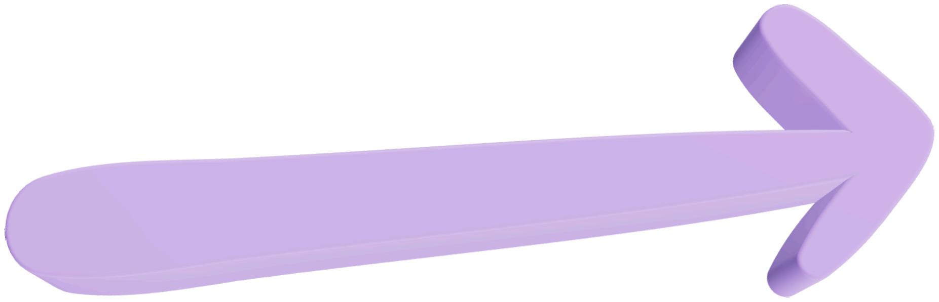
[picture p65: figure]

# MARKET COMPETITORS

## G O F R

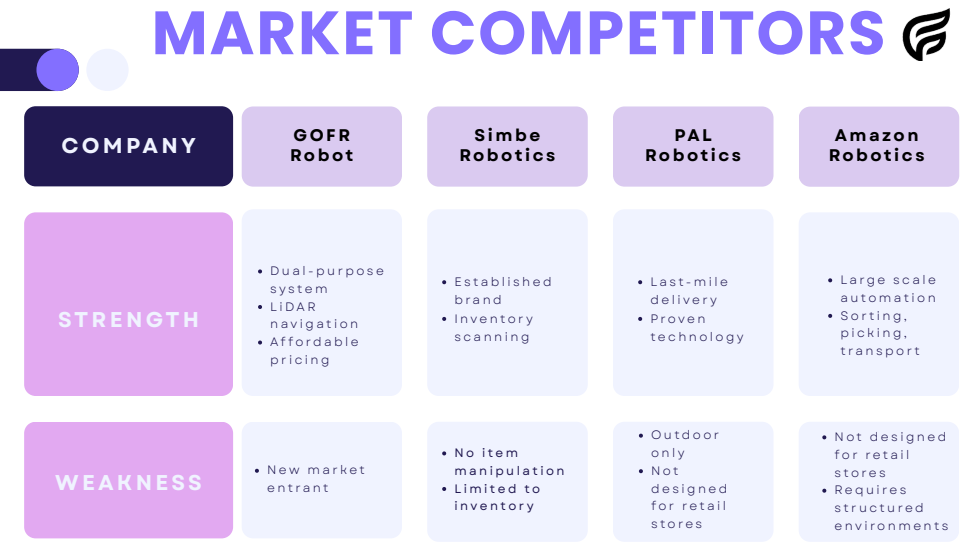
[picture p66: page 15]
C OMPANY; WE A KNESS

Simb e
Ro b ot ics

Amazon

ST R EN GTH

# REVENUE MODEL

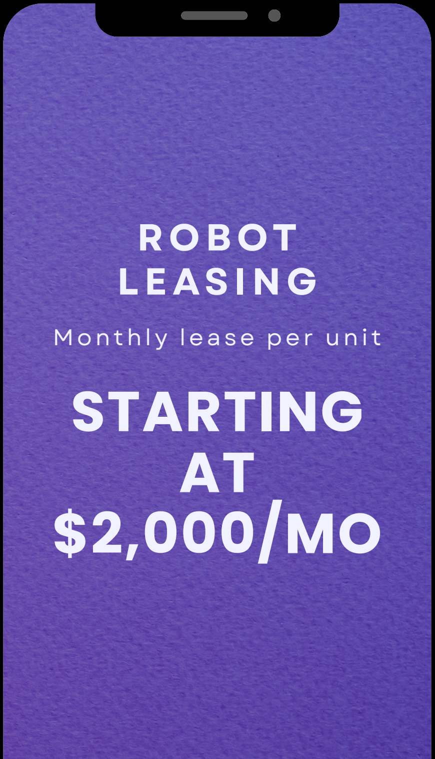
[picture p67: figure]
STARTING AT $2,000/MO; Monthl y lease per uni t; R O B OT LE ASIN G

### Free 1 month t r ial

### Labor cost reduct ion:

### Target Mar ket Si ze ( US G rocer y)

### 5-Year Revenue Target

### *Detail in the next p age

### 7 0% monthly (Work d ou b le shi f t + chea p er than minimum wage)

### 66,0 0 0 + stores * *

### $1 1 0M A R R b ase d on a 1% convers ion rate wi thin the a d vance d - t ier p ackage

segment .

### Free C overage over 3 years and annual checkups

# R E V ENU E ST R E AMS:

## Su b scr i pt ion Services (Main)

## Store Savings

## Market Potent ial

## Maintenance C ont ract s

### $9 0 0 Billion*

### $93 0 0 0 p er year

* source for mar ket s i ze:
ht tps : / / w w w. ibi swor ld.com/uni ted-states /mar ket- s i ze/ supermar ket s -grocer y- stores / 1040/
* * source for the number of stores :
ht tps : / / w w w.stat i sta.com/ topics / 1660 / food- retai l /

### $24,0 0 0 (~4 0% margin)

## Di rect - sell

# ROBOTS AS A SERVICE (RAAS)

### N e w m a r k e t e n t r a n t

### N e w m a r k e t e n t r a n t

Package Level | Features | Pr ice p er month

# B a s i c 1

# B a s i c 2

# A d v a n c e d

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

$ 2 0 0 0

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

$ 2 0 0 0

$ 3 0 0 0

$ 1 2 0 0 0

# THANK YOU

C onnect; G i thu b We b s i te

Ready to Transform G rocer y O perat ions

# THANKYOU

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

# THANKYOU

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

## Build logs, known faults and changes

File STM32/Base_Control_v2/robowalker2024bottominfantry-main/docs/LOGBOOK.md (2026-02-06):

# RoboWalker 2024 Bottom Infantry – Engineering Logbook

_Last updated: 2026-01-20_

This logbook consolidates the control architecture, firmware layout, communication protocols, toolchain, and notable debug sessions for the STM32-based bottom infantry chassis. It is intended as a “ready-to-hand” reference when onboarding new teammates, replicating the build, or integrating higher-level systems (e.g., Jetson ROS 2).

---

## 1. Project Overview

| Aspect | Description |
| --- | --- |
| MCU | STM32F427, Keil MDK target `test` |
| Chassis | 4-wheel mecanum (C620 + M3508), CAN1 bus IDs 0x201–0x204 |
| Host I/O | UART2 (115200 bps) for PC/Jetson control + Serialplot telemetry |
| Scheduler | TIM5 @ 1 kHz (alive checks, slope planning, CAN send); TIM4 @ 10 kHz (reserved) |
| Toolchain | Keil ARMCC 5.06 Update 6, CubeMX `.ioc`, Serialplot for telemetry |
| Repo layout | `test/Core` (Cube HAL), `test/User_File` (middleware & control), `docs` (specs) |

### Control Flow Snapshot
1. `main.c` → `Task_Init()` (BSP, CAN, UART, timers, watchdog, Serialplot, robot init).
2. TIM5 interrupt (`Task1ms_TIM5_Callback()`): alive counters (100 ms / 1 s), 10 ms logic, 2 ms chassis control, 1 ms PC parse + slope planning. Serialplot + CAN/UART/WDG services also run here.
3. Chassis loop (every 2 ms):
   - `Self_Resolution()` – wheel odometry (with wiring sign compensation).
   - `Kinematics_Inverse_Resolution()` – mecanum equations.
   - `Output_To_Dynamics()` – outer PID on vx/vy/omega.
   - `Dynamics_Inverse_Resolution()` – per-wheel current target.
   - `_Power_Limit_Control()` + CAN send.
4. PC UART2 input is parsed via DMA receive-to-idle. Valid frames update `Class_PC`; invalid ones fall back to Serialplot parser.

---

## 2. Key Modules & Algorithms

### 2.1 Class_PC (PC UART bridge)
- **Frame**: `0xAC` header + 5 floats (rightX/rightY/leftX/leftY/yaw) + uint16 keyboard mask + 2 switch bytes + checksum.
- **Timing**: frames expected at ≥10 Hz; alive watchdog disables chassis if no increment in 100 ms.
- **Edge detection**: `TIM_1ms_Calculate_PeriodElapsedCallback()` compares current vs previous mask/switch to generate DR16-style triggers.
- **Integration points**: `PC.Get_Left_X/Y`, `PC.Get_Yaw`, `Get_Keyboard_Key_*`, left switch gating in `_Chassis_Control()` (safety).

### 2.2 Class_Chassis
- **Geometry**: R = 0.0762 m, half-length 0.1905 m, half-width 0.3175 m.
- **Direction map**: `constexpr int8_t Wheel_Direction[4] = {+1, -1, +1, -1}` for FL/FR/RL/RR wiring.
- **Forward kinematics**: using signed omegas `s_i * w_i` to compute body velocity and yaw rate.
- **Inverse kinematics**: standard mecanum equations; direction signs applied only at motor command stage to avoid distorting dynamics/PIDs.
- **Dynamics inversion**: `force_x/y` and `torque` from outer PIDs → per-wheel current with slip correction (`Wheel_Speed_Limit_Factor`) + dynamic friction compensation.
- **Power limiting**: motor power estimation (from C620 feedback) allows dynamic scaling via `_Power_Limit_Control()`.

### 2.3 Motor Stack (C620 + M3508)
- `dvc_motor_dji.cpp` provides cascaded control: angle → omega → current (only current loop active in chassis mode).
- CAN commands: ID 0x200 (four int16 currents). Feedback frames 0x201–0x204 parsed to angle/omega/current/temperature, including power estimation for limit control.

### 2.4 PID & Slope
- `alg_pid`: configurable dead-zone, variable integration rate, derivative-on-measurement, feedforward term.
- `Class_Slope`: soft-start ramp for vx/vy/omega targets (configured in `Class_Robot::Init()`), smoothing PC commands.

---

## 3. Host Interfaces

### 3.1 UART2 (PC/Jetson Control)

| Parameter | Value |
| --- | --- |
| Baud | 115 200 (8-N-1) |
| Header | 0xAC |
| Payload | RightX, RightY, LeftX, LeftY, Yaw (float32) + Keyboard Mask (uint16) + Switch L/R (uint8) |
| Checksum | 8-bit sum over payload |
| Frame size | 26 bytes |

Keyboard mask (bit → action):

| Bit | Key | Action |
| --- | --- | --- |
|0|W|Left stick Y +1 (forward)|
|1|S|Left stick Y −1 (reverse)|
|2|A|Left stick X −1 (strafe left)|
|3|D|Left stick X +1 (strafe right)|
|4|Shift|Boost mode (higher velocity & omega limits)|
|5|Ctrl|Reserved|
|6|Q|Yaw −1 (CCW spin)|
|7|E|Yaw +1 (CW spin)|
|8‑15|R/F/G/Z/X/C/V/B|Reserved (future toggles)|

Switch encoding uses DR16 semantics (1=UP, 2=MID, 3=DOWN). Left switch DOWN or PC offline disables chassis output.

Serialplot telemetry (STM32 → host): 6 floats (target vx/vy/omega and measured vx/vy/omega) at 200 Hz. Frame format is `0xAB + 24-byte payload + 8-bit checksum`.

### 3.2 CAN1 (Wheel Motors)
- Bus speed: 1 Mbps.
- Command frame (ID 0x200): `[I_FL, I_FR, I_RL, I_RR]` as int16 currents (big-endian).
- Feedback frames (0x201–0x204): `[encoder, speed, current, temp, reserved]`.
- Direction signs already applied in firmware; host-level CAN tools may treat positive current as “chassis forward” for all wheels.

---

## 4. Toolchain & Utilities

| Tool | Purpose |
| --- | --- |
| Keil MDK (ARMCC 5.06u6) | Build + flash (`test.uvprojx` target). |
| STM32CubeMX | `test/test.ioc` as configuration reference. |
| Serialplot | UART2 telemetry visualization. |
| `tools/pc_control.py` | Python host script (pynput + pyserial) for keyboard teleoperation. Defaults: COM14, 115200, 50 Hz. |
| ROS 2 (planned) | Jetson integration—reuse UART2 frame format inside a ROS node. |

---

## 5. Debug & Experiment Log (selected entries)

| Date | Issue | Investigation | Resolution |
| --- | --- | --- | --- |
| 2026-01-19 | Right wheels spin backwards when moving forward. | Verified CAN IDs (0x202/0x204) physically reversed. Observed `Chassis_Control_Type_DISABLE` gating when PC offline. | Added `Wheel_Direction` map; first attempt applied signs multiple times causing speed mismatch. Final approach: apply sign only when sampling encoder (`Self_Resolution`) and when commanding currents (`Output_To_Motor`); keep core kinematics in uniform frame. |
| 2026-01-19 | Keil error “Cannot open file test\test.axf”. | Build log showed linking error `Undefined symbol Class_Chassis::Wheel_Direction`. | Added `constexpr int8_t Class_Chassis::Wheel_Direction[4];` definition in `crt_chassis.cpp`. |
| 2026-01-19 | Serial write timeout from `pc_control.py` on COM14. | Determined mismatched baud (MCU 1 Mbps, PC set default COM14). | Reduced USART2 baud to 115200 (CubeMX, HAL init, Python defaults) to match USB-UART dongle capability. |
| 2026-01-20 | Documentation gaps for ROS/Jetson integration. | Compiled `CONTROL_LOGIC.md` and `INTERFACES_PC_CAN.md`; added keyboard-to-action mapping, UART/CAN specs. | Created `LOGBOOK.md` + interface doc to support future ROS2 bridge. |

Future TODOs (tracked here for quick reference):
- Re-enable supercap/referee/manifold logic once hardware is available.
- Consider micro-ROS or native ROS2 bridge if Jetson ↔ MCU latency becomes critical.
- Expand Serialplot channels with battery/temperature telemetry, or replace with ROS2 diagnostics.

---

## 6. Integration Notes for Jetson ROS 2

1. **Serial node**: Use `rclpy`/`rclcpp` + `pyserial` to open `/dev/ttyUSBx` @ 115200. Publish `/cmd_vel` → frame builder, subscribe to `/chassis/odom` if feedback is implemented.
2. **Protocol reuse**: Keep frame layout identical to `pc_control.py` to avoid firmware changes.
3. **Safety**: Monitor `PC_Status` by adding a return frame or dedicating a Serialplot channel; stop sending commands if MCU reports disable.
4. **Testing**: Start with loopback on PC, then move to Jetson, verifying checksum and frame rate with logic analyzer or serial sniffer.

---

## 7. Repository Structure Cheat Sheet

```
├── test/
│   ├── Core/             # Cube HAL sources
│   ├── User_File/
│   │   ├── 1_Middleware/ # Drivers (CAN/UART/TIM/BSP), Algorithms (PID/Slope)
│   │   ├── 2_Device/     # Device abstractions (PC UART, DJI motors, Serialplot)
│   │   ├── 3_Chariot/    # Chassis modules
│   │   ├── 4_Interaction/# Robot orchestration
│   │   └── 5_Task/       # Scheduler, callbacks
│   └── MDK-ARM/          # Keil project files
├── tools/pc_control.py   # Host keyboard control script
└── docs/                 # CONTROL_LOGIC.md, INTERFACES_PC_CAN.md, LOGBOOK.md
```

---

## 8. Quick Reference (cheat table)

| Hotkey | Effect | Notes |
| --- | --- | --- |
| W / S | Move forward / backward | Continuous while held; filtered by slope planner. |
| A / D | Strafe left / right | Same magnitude as W/S. |
| Q / E | Spin CCW / CW | Maps to yaw command ±1. |
| Shift | Boost mode | `_Chassis_Control` raises target limits + slope rate. |
| Left switch DOWN | Disable chassis | Safety interlock. |
| PC frame loss >100 ms | Disable chassis | Alive timer triggers `UART_Reinit`. |

---

## 9. Contacts & Maintenance

| Area | Owner | Notes |
| --- | --- | --- |
| STM32 firmware | Team 21 embedded group | Keep `test` target synced with `Base_Control` if features diverge. |
| Jetson / ROS bridge | TBD | Follow UART & CAN specs; contributions welcome. |
| Documentation | Repo maintainers | Update `LOGBOOK.md` + interface docs when protocols or scheduling change. |

---

_End of logbook._

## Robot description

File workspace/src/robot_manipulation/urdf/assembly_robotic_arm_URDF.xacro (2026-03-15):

<?xml version="1.0" ?>
<robot name="assembly_robotic_arm_URDF" xmlns:xacro="http://www.ros.org/wiki/xacro">

<xacro:include filename="materials.xacro" />
<link name="base_link">
  <inertial>
    <origin xyz="0.025568174865929133 -0.037161526078087564 0.07690409937696371" rpy="0 0 0"/>
    <mass value="3.600452366591152"/>
    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
  </inertial>
  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
</link>

<link name="inner-ring_1">
  <inertial>
    <origin xyz="-8.7442074626215e-08 -0.004780885684227354 -8.464326463342164e-08" rpy="0 0 0"/>
    <mass value="0.23504555627740456"/>
    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
  </inertial>
  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
</link>

<link name="outer-ring_1">
  <inertial>
    <origin xyz="-8.744207051145092e-08 0.004729729493174445 -8.464319313505886e-08" rpy="0 0 0"/>
    <mass value="0.3586130491956171"/>
    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
  </inertial>
  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
</link>

<link name="RDS_Servo_1">
  <inertial>
    <origin xyz="-8.74420677393628e-08 0.037445726417167785 -8.464323357493253e-08" rpy="0 0 0"/>
    <mass value="0.5488799503959932"/>
    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
  </inertial>
  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
</link>

<link name="base-linkage_1">
  <inertial>
    <origin xyz="1.1941234743215873e-05 0.07499992129458155 -1.2318574447722774e-06" rpy="0 0 0"/>
    <mass value="0.11126416203116223"/>
    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
  </inertial>
  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
</link>

<link name="bearing-base-interface_1">
  <inertial>
    <origin xyz="2.980935244515162e-05 0.003476899701562078 -2.935998278344454e-06" rpy="0 0 0"/>
    <mass value="0.37789173913859087"/>
    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
  </inertial>
  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
</link>

<link name="20kg_Servo_1">
  <inertial>
    <origin xyz="2.9679660253356666e-06 -0.02268054621276394 3.17635125227228e-05" rpy="0 0 0"/>
    <mass value="0.28545564068627766"/>
    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
  </inertial>
  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
</link>

<link name="lower_1">
  <inertial>
    <origin xyz="0.03225199837408904 0.17854870535469428 -0.285857828694417" rpy="0 0 0"/>
    <mass value="0.1298002433404817"/>
    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
  </inertial>
  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
</link>

<link name="RDS_Servo_2">
  <inertial>
    <origin xyz="-0.03727688581107813 -2.55079023125937e-07 0.003555508152516984" rpy="0 0 0"/>
    <mass value="0.5488799503959932"/>
    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
  </inertial>
  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
</link>

<link name="upper_1">
  <inertial>
    <origin xyz="0.1484516478586171 -0.029701340692169453 0.014305457848267394" rpy="0 0 0"/>
    <mass value="0.18540415998295687"/>
    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
  </inertial>
  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
</link>

<joint name="joint1_base_yaw" type="continuous">
  <origin xyz="0.0 0.0095 0.0" rpy="0 0 0"/>
  <parent link="outer-ring_1"/>
  <child link="inner-ring_1"/>
  <axis xyz="-0.0 1.0 -0.0"/>
</joint>

<joint name="rigid_11" type="fixed">
  <origin xyz="0.025231 0.004807 0.077778" rpy="0 0 0"/>
  <parent link="base_link"/>
  <child link="outer-ring_1"/>
</joint>

<joint name="rigid_12" type="fixed">
  <origin xyz="0.0 0.15 0.0" rpy="0 0 0"/>
  <parent link="base-linkage_1"/>
  <child link="RDS_Servo_1"/>
</joint>

<joint name="rigid_13" type="fixed">
  <origin xyz="0.0 0.007 0.0" rpy="0 0 0"/>
  <parent link="bearing-base-interface_1"/>
  <child link="base-linkage_1"/>
</joint>

<joint name="rigid_14" type="fixed">
  <origin xyz="0.0 0.0 0.0" rpy="0 0 0"/>
  <parent link="inner-ring_1"/>
  <child link="bearing-base-interface_1"/>
</joint>

<joint name="rigid_15" type="fixed">
  <origin xyz="0.03224 0.091053 -0.285857" rpy="0 0 0"/>
  <parent link="lower_1"/>
  <child link="20kg_Servo_1"/>
</joint>

<joint name="joint2_shoulder" type="continuous">
  <origin xyz="-0.112567 -0.251998 0.293513" rpy="0 0 0"/>
  <parent link="RDS_Servo_2"/>
  <child link="lower_1"/>
  <axis xyz="0.094942 0.0 0.995483"/>
</joint>

<joint name="rigid_18" type="fixed">
  <origin xyz="0.024037 -0.029689 0.026171" rpy="0 0 0"/>
  <parent link="upper_1"/>
  <child link="RDS_Servo_2"/>
</joint>

<joint name="joint3_elbow" type="continuous">
  <origin xyz="-0.25355 0.11038 -0.004287" rpy="0 0 0"/>
  <parent link="RDS_Servo_1"/>
  <child link="upper_1"/>
  <axis xyz="0.094942 0.0 0.995483"/>
</joint>

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

</robot>

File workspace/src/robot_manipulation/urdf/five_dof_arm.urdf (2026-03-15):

<?xml version="1.0"?>
<robot name="five_dof_arm">

  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
  <link name="base_link">
    <inertial>
      <origin xyz="0 0 0" rpy="0 0 0"/>
      <mass value="2.0"/>
      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
    </inertial>
    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
  </link>

  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
  <link name="link1_tower">
    <inertial>
      <origin xyz="0 0 0.1" rpy="0 0 0"/>
      <mass value="1.0"/>
      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
    </inertial>
    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
  </link>

  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
  <link name="link2_upper_arm">
    <inertial>
      <origin xyz="0.15 0 0" rpy="0 0 0"/>
      <mass value="0.8"/>
      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
    </inertial>
    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
  </link>

  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
  <link name="link3_forearm">
    <inertial>
      <origin xyz="0.15 0 0" rpy="0 0 0"/>
      <mass value="0.7"/>
      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
    </inertial>
    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
  </link>

  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
  <link name="link4_wrist">
    <inertial>
      <origin xyz="0.05 0 0" rpy="0 0 0"/>
      <mass value="0.3"/>
      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
    </inertial>
    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
  </link>

  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
  <link name="gripper_base">
    <inertial>
      <origin xyz="0.02 0 0" rpy="0 0 0"/>
      <mass value="0.2"/>
      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
    </inertial>
    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
  </link>

  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
  <link name="gripper_finger1">
    <inertial>
      <origin xyz="0.04 0 0" rpy="0 0 0"/>
      <mass value="0.05"/>
      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
    </inertial>
    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
  </link>

  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
  <link name="gripper_finger2">
    <inertial>
      <origin xyz="0.04 0 0" rpy="0 0 0"/>
      <mass value="0.05"/>
      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
    </inertial>
    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
  </link>

  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
  <joint name="joint1_base_yaw" type="revolute">
    <parent link="base_link"/>
    <child link="link1_tower"/>
    <origin xyz="0 0 0.05" rpy="0 0 0"/>
    <axis xyz="0 0 1"/>
    <dynamics damping="0.1" friction="0.1"/>
    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
    <limit lower="-2.3562" upper="2.3562" effort="50.0" velocity="2.0"/>
  </joint>

  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
  <joint name="joint2_shoulder" type="revolute">
    <parent link="link1_tower"/>
    <child link="link2_upper_arm"/>
    <origin xyz="0 0 0.2" rpy="0 0 0"/>
    <axis xyz="0 1 0"/>
    <dynamics damping="0.1" friction="0.1"/>
    <limit lower="-1.5708" upper="1.5708" effort="50.0" velocity="2.0"/>
  </joint>

  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
  <joint name="joint3_elbow" type="revolute">
    <parent link="link2_upper_arm"/>
    <child link="link3_forearm"/>
    <origin xyz="0.3 0 0" rpy="0 0 0"/>
    <axis xyz="0 1 0"/>
    <dynamics damping="0.1" friction="0.1"/>
    <limit lower="0.0" upper="2.3562" effort="40.0" velocity="2.0"/>
  </joint>

  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
  <joint name="joint4_wrist_roll" type="revolute">
    <parent link="link3_forearm"/>
    <child link="link4_wrist"/>
    <origin xyz="0.3 0 0" rpy="0 0 0"/>
    <axis xyz="0 0 1"/>
    <dynamics damping="0.1" friction="0.1"/>
    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
    <limit lower="-2.3562" upper="2.3562" effort="30.0" velocity="3.0"/>
  </joint>

  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
  <joint name="joint_gripper_mount" type="fixed">
    <parent link="link4_wrist"/>
    <child link="gripper_base"/>
    <origin xyz="0.1 0 0" rpy="0 0 0"/>
  </joint>

  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
  <joint name="joint5_gripper" type="revolute">
    <parent link="gripper_base"/>
    <child link="gripper_finger1"/>
    <origin xyz="0.02 0.015 0" rpy="0 0 0"/>
    <axis xyz="0 1 0"/>
    <dynamics damping="0.1" friction="0.1"/>
    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
    <limit lower="0.0" upper="0.8" effort="10.0" velocity="3.0"/>
  </joint>

  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
  <joint name="joint5_gripper_mimic" type="revolute">
    <parent link="gripper_base"/>
    <child link="gripper_finger2"/>
    <origin xyz="0.02 -0.015 0" rpy="0 0 0"/>
    <axis xyz="0 1 0"/>
    <dynamics damping="0.1" friction="0.1"/>
    <limit lower="-0.8" upper="0.0" effort="10.0" velocity="3.0"/>
    <mimic joint="joint5_gripper" multiplier="-1.0" offset="0.0"/>
  </joint>
  
  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

</robot>

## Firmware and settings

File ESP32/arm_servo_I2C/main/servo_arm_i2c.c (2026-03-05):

#include <string.h>
#include <stdbool.h>

#include "freertos/FreeRTOS.h"
#include "freertos/task.h"

#include "driver/gpio.h"
#include "driver/ledc.h"
#include "driver/i2c.h"
#include "esp_err.h"
#include "esp_log.h"

/* ------------------------------ Log Tag ----------------------------------- */
static const char *TAG = "servo_i2c_controller";

/* ------------------------------ Servo PWM ---------------------------------- */
#define SERVO_TIMER_MODE       LEDC_LOW_SPEED_MODE
#define SERVO_TIMER_ID         LEDC_TIMER_0
#define SERVO_TIMER_RES        LEDC_TIMER_16_BIT   // Higher resolution for servos
#define SERVO_PWM_FREQ_HZ      50                  // 50Hz servo
#define SERVO_MAX_DUTY         ((1U << SERVO_TIMER_RES) - 1U)

#define SERVO_MIN_US           500
#define SERVO_MAX_US           2500
#define SERVO_PERIOD_US        20000   // 20ms = 50Hz

/* ------------------------- Servo GPIO assignments -------------------------- */
/*  CHANGE THESE TO YOUR REAL SERVO PINS  */
#define SERVO_1_GPIO    GPIO_NUM_25
#define SERVO_2_GPIO    GPIO_NUM_26
#define SERVO_3_GPIO    GPIO_NUM_27
#define SERVO_4_GPIO    GPIO_NUM_32
#define SERVO_5_GPIO    GPIO_NUM_33

/* --------------------------- Servo channel struct -------------------------- */
typedef struct {
    gpio_num_t gpio;
    ledc_channel_t channel;
} servo_channel_t;

enum {
    SERVO_1 = 0,
    SERVO_2,
    SERVO_3,
    SERVO_4,
    // SERVO_5,
    SERVO_COUNT
};

static const servo_channel_t s_servo_channels[SERVO_COUNT] = {
    [SERVO_1] = { SERVO_1_GPIO, LEDC_CHANNEL_0 },
    [SERVO_2] = { SERVO_2_GPIO, LEDC_CHANNEL_1 },
    [SERVO_3] = { SERVO_3_GPIO, LEDC_CHANNEL_2 },
    [SERVO_4] = { SERVO_4_GPIO, LEDC_CHANNEL_3 },
    // [SERVO_5] = { SERVO_5_GPIO, LEDC_CHANNEL_4 }, (if add the gripper rotation)
};

/* ------------------------------ I2C Slave ---------------------------------- */
#define I2C_SLAVE_NUM           I2C_NUM_0
#define I2C_SLAVE_SDA_IO        GPIO_NUM_8
#define I2C_SLAVE_SCL_IO        GPIO_NUM_9
#define I2C_SLAVE_ADDR          0x08

/* Buffer for 5 float angles received from Jetson */
static float s_servo_targets[SERVO_COUNT] = {0};

/* ---------------------- Utility: angle → microseconds ---------------------- */
static inline int angle_to_us(float angle)
{
    if (angle < 0) angle = 0;
    if (angle > 180) angle = 180;
    return SERVO_MIN_US +
           (int)(angle * (SERVO_MAX_US - SERVO_MIN_US) / 180.0f);
}

/* ---------------------- Utility: microseconds → duty ----------------------- */
static inline uint32_t us_to_duty(int us)
{
    return (uint32_t)(((float)us / SERVO_PERIOD_US) * SERVO_MAX_DUTY);
}

/* ----------------------------- Servo Write --------------------------------- */
static void servo_write_angle(int id, float angle)
{
    int us = angle_to_us(angle);
    uint32_t duty = us_to_duty(us);

    ledc_set_duty(SERVO_TIMER_MODE, s_servo_channels[id].channel, duty);
    ledc_update_duty(SERVO_TIMER_MODE, s_servo_channels[id].channel);
}

/* ------------------------------- Init Servos ------------------------------- */
static esp_err_t servo_init(void)
{
    // Configure LEDC timer
    ledc_timer_config_t timer_cfg = {
        .speed_mode       = SERVO_TIMER_MODE,
        .timer_num        = SERVO_TIMER_ID,
        .duty_resolution  = SERVO_TIMER_RES,
        .freq_hz          = SERVO_PWM_FREQ_HZ,
        .clk_cfg          = LEDC_AUTO_CLK,
    };
    ESP_ERROR_CHECK(ledc_timer_config(&timer_cfg));

    // Configure all servo channels
    for (int i = 0; i < SERVO_COUNT; ++i) {
        ledc_channel_config_t ch_cfg = {
            .gpio_num   = s_servo_channels[i].gpio,
            .speed_mode = SERVO_TIMER_MODE,
            .channel    = s_servo_channels[i].channel,
            .timer_sel  = SERVO_TIMER_ID,
            .duty       = 0,
            .hpoint     = 0,
        };
        ESP_ERROR_CHECK(ledc_channel_config(&ch_cfg));
    }

    ESP_LOGI(TAG, "Servos initialized.");
    return ESP_OK;
}

/* ------------------------------- Init I2C ---------------------------------- */
static esp_err_t i2c_init(void)
{
    i2c_config_t slave_cfg = {
        .mode = I2C_MODE_SLAVE,
        .sda_io_num = I2C_SLAVE_SDA_IO,
        .sda_pullup_en = GPIO_PULLUP_ENABLE,
        .scl_io_num = I2C_SLAVE_SCL_IO,
        .scl_pullup_en = GPIO_PULLUP_ENABLE,
        .slave = {
            .slave_addr = I2C_SLAVE_ADDR,
            .addr_10bit_en = 0,
        },
    };

    ESP_ERROR_CHECK(i2c_param_config(I2C_SLAVE_NUM, &slave_cfg));
    ESP_ERROR_CHECK(i2c_driver_install(
        I2C_SLAVE_NUM, I2C_MODE_SLAVE,
        256, 256, 0
    ));

    ESP_LOGI(TAG, "I2C slave initialized on addr 0x%02X.", I2C_SLAVE_ADDR);
    return ESP_OK;
}

/* ------------------------------- I2C Task ---------------------------------- */
static void i2c_task(void *arg)
{
    uint8_t rxbuf[20];  // 5 floats * 4 bytes
    const size_t expected = sizeof(rxbuf);

    while (true)
    {
        int len = i2c_slave_read_buffer(I2C_SLAVE_NUM, rxbuf, expected, portMAX_DELAY);

        if (len == expected) {
            memcpy(s_servo_targets, rxbuf, expected);

            ESP_LOGI(TAG, "Angles: %.1f %.1f %.1f %.1f %.1f",
                     s_servo_targets[0],
                     s_servo_targets[1],
                     s_servo_targets[2],
                     s_servo_targets[3],
                     //s_servo_targets[4]
                    );

            // Write servos
            for (int i = 0; i < SERVO_COUNT; i++)
                servo_write_angle(i, s_servo_targets[i]);
        }
        else {
            ESP_LOGW(TAG, "Received unexpected length: %d", len);
        }
    }
}

/* -------------------------------- app_main --------------------------------- */
void app_main(void)
{
    ESP_LOGI(TAG, "Starting 5-servo I2C controller");

    ESP_ERROR_CHECK(servo_init());
    ESP_ERROR_CHECK(i2c_init());

    xTaskCreate(i2c_task, "i2c_task", 4096, NULL, 10, NULL);

    while (true) {
        vTaskDelay(pdMS_TO_TICKS(1000));
    }
}

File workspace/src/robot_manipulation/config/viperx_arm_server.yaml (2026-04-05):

viperx_arm_server:
  ros__parameters:
    action_name: "pick_viperx"
    arm_group_name: "interbotix_arm"
    gripper_group_name: "interbotix_gripper"

    planning_time_sec: 3.0
    max_velocity_scaling: 0.2
    max_acceleration_scaling: 0.2
    enforce_orientation_path_constraint: false
    enforce_orientation_path_constraint_on_pose_moves: false
    use_position_target_with_orientation_constraint: true
    allow_orientation_constraint_fallback: false
    orientation_constraint_x_tolerance_rad: 0.20
    orientation_constraint_y_tolerance_rad: 0.20
    orientation_constraint_z_tolerance_rad: 0.20
    orientation_constraint_weight: 1.0
    preview_only: false
    preview_step_delay_sec: 1.0
    verify_final_orientation_match: true
    orientation_check_settle_sec: 0.15

    # Fallback values used if named targets are not available in the SRDF.
    open_gripper_pos: 0.035
    closed_gripper_pos: 0.040
    scan_center_joint_names: ["waist", "shoulder", "elbow", "forearm_roll", "wrist_angle", "wrist_rotate"]
    scan_center_joint_positions: [0.0, -1.34390352, 1.57079633, 0.0, -0.22689280, 0.0]
    scan_left_joint_names: ["waist", "shoulder", "elbow", "forearm_roll", "wrist_angle", "wrist_rotate"]
    scan_left_joint_positions: [0.78539816, -1.34390352, 1.57079633, 0.0, -0.22689280, 0.0]
    scan_right_joint_names: ["waist", "shoulder", "elbow", "forearm_roll", "wrist_angle", "wrist_rotate"]
    scan_right_joint_positions: [-0.78539816, -1.34390352, 1.57079633, 0.0, -0.22689280, 0.0]
    startup_joint_names: ["waist", "shoulder", "elbow", "forearm_roll", "wrist_angle", "wrist_rotate"]
    startup_joint_positions: [0.0, -1.85004901, 1.57079633, 0.0, 0.40142573, 0.0]
    restock_pick_ready_joint_positions: [0.0, -1.06465084, 1.02974426, 0.0, 0.54105207, 0.0]
    restock_pick_approach_joint_positions: [2.39110108, -1.23918377, 1.30899694, 1.46607657, -0.83775804, -1.43116999]
    restock_pick_joint_positions: [1.98967535, 0.05235988, 1.55334303, 0.43633231, -1.62315620, 0.01745329]
    restock_post_pick_joint_positions: [2.42600766, -1.23918377, 1.09955743, 1.65806279, -0.87266463, -1.72787596]
    restock_transfer_joint_positions: [0.12217305, -0.54105207, 0.85521133, 0.41887902, -0.33161256, -0.36651914]
    restock_place_joint_positions: [0.15707963, 0.19198622, 0.29670597, 0.29670597, -0.61086524, -0.22689280]
    restock_home_joint_positions: [0.0, -1.85004901, 1.57079633, 0.0, 0.73303829, 0.0]
    place_joint_names: ["waist", "shoulder", "elbow", "forearm_roll", "wrist_angle", "wrist_rotate"]
    place_joint_positions: [2.63544717, -0.43633231, 1.22173048, 1.23918377, -1.25663706, -0.76794487]
    place_2_joint_positions: [3.14159265, -0.50614548, 1.25663706, 1.58824962, -1.60570291, -0.83775804]
    place_3_joint_positions: [1.76278254, -1.01229097, 1.43116999, 0.40142573, -0.45378561, -0.38397244]
    place_4_joint_positions: [3.05432619, -1.34390352, 1.48352986, 1.57079633, -1.51843645, -1.44862328]
    place_5_joint_positions: [0.57595865, -0.68067841, 1.32645023, -1.22173048, -1.13446401, 0.82030475]
    place_6_joint_positions: [-0.27925268, -0.75049158, 1.34390352, -1.74532925, -1.79768913, 0.90757121]
    post_place_joint_names: ["waist", "shoulder", "elbow", "forearm_roll", "wrist_angle", "wrist_rotate"]
    post_place_joint_positions: [1.81514242, -1.06465084, 1.16937060, 0.43633231, -0.15707963, -0.41887902]
    pre_return_joint_names: ["waist", "shoulder", "elbow", "forearm_roll", "wrist_angle", "wrist_rotate"]
    pre_return_joint_positions: [0.0, -1.37881011, 1.20427718, 0.0, 0.27925268, 0.0]
    return_joint_names: ["waist", "shoulder", "elbow", "forearm_roll", "wrist_angle", "wrist_rotate"]
    return_joint_positions: [0.0, -1.85004901, 1.53588974, 0.0, 0.80285146, 0.0]
    lift_joint_names: ["waist", "shoulder", "elbow", "forearm_roll", "wrist_angle", "wrist_rotate"]
    lift_joint_positions: [0.0, -0.17453293, 1.39626340, 0.0, -1.20427718, 0.0]
    post_lift_joint_names: ["waist", "shoulder", "elbow", "forearm_roll", "wrist_angle", "wrist_rotate"]
    post_lift_joint_positions: [0.0, -0.82030475, 1.06465084, 0.0, -0.24434610, 0.0]

    # Interbotix SRDF defaults for gripper group states.
    open_gripper_named_target: "Released"
    close_gripper_named_target: ""

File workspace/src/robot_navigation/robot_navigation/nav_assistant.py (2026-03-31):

#!/usr/bin/env python3
"""
Unified workflow helper for the Team 21 navigation stack.

This script wraps the runbook in Nav/README_SLAM_UPDATED.md into short commands:
- one-line launch for mapping and localization+Nav2
- map save/export
- Nav2 goal/waypoint sending
- preset motion macros and keyboard macro pad
"""

from __future__ import annotations

import argparse
import math
import select
import shlex
import subprocess
import sys
import termios
import time
import tty
from dataclasses import dataclass
from pathlib import Path
from typing import Dict, List, Sequence, Tuple

import rclpy
from action_msgs.msg import GoalStatus
from geometry_msgs.msg import PoseStamped, Twist
from nav2_msgs.action import FollowWaypoints, NavigateToPose
from rclpy.action import ActionClient
from rclpy.node import Node


def _find_repo_root() -> Path:
    here = Path(__file__).resolve()
    for parent in [here.parent, *here.parents]:
        if (
            (parent / "Nav").exists()
            and (parent / "Maps").exists()
            and (parent / "workspace").exists()
        ):
            return parent
    cwd = Path.cwd()
    if (cwd / "Nav").exists() and (cwd / "Maps").exists():
        return cwd
    return cwd


REPO_ROOT = _find_repo_root()
DEFAULT_MAPS_DIR = str(REPO_ROOT / "Maps")
DEFAULT_MAP_NAME = "testmapMain"
DEFAULT_CMD_TOPICS = '["/cmd_vel","/cmd_vel_nav","/cmd_vel_smoothed"]'
DEFAULT_LOCALIZATION_CMD_TOPICS = '["/cmd_vel"]'
DEFAULT_RUN_MODE = "normal"
RUN_MODES = ("normal", "bench")
MAPPING_CONFIG_BASENAME = {
    "normal": "pico_2d.lua",
    "bench": "pico_2d_bench.lua",
}
LOCALIZATION_CONFIG_BASENAME = {
    "normal": "pico_2d_localization.lua",
    "bench": "pico_2d_localization_bench.lua",
}


def yaw_to_quaternion(yaw: float) -> Tuple[float, float, float, float]:
    half = yaw * 0.5
    return 0.0, 0.0, math.sin(half), math.cos(half)


def parse_pose(text: str) -> Tuple[float, float, float]:
    parts = [p.strip() for p in text.split(",")]
    if len(parts) != 3:
        raise argparse.ArgumentTypeError(
            f"Invalid pose '{text}'. Expected format: x,y,yaw"
        )
    try:
        return float(parts[0]), float(parts[1]), float(parts[2])
    except ValueError as exc:
        raise argparse.ArgumentTypeError(
            f"Invalid numeric values in pose '{text}'"
        ) from exc


def parse_bool(value: str) -> bool:
    normalized = value.strip().lower()
    if normalized in ("1", "true", "t", "yes", "y", "on"):
        return True
    if normalized in ("0", "false", "f", "no", "n", "off"):
        return False
    raise argparse.ArgumentTypeError(f"Invalid boolean value '{value}'")


def parse_segment(text: str) -> "MotionSegment":
    parts = [p.strip() for p in text.split(",")]
    if len(parts) != 4:
        raise argparse.ArgumentTypeError(
            f"Invalid segment '{text}'. Expected: vx,vy,wz,duration_sec"
        )
    try:
        vx, vy, wz, duration = (float(v) for v in parts)
    except ValueError as exc:
        raise argparse.ArgumentTypeError(
            f"Invalid numeric values in segment '{text}'"
        ) from exc
    if duration <= 0.0:
        raise argparse.ArgumentTypeError("Segment duration must be > 0")
    return MotionSegment(vx=vx, vy=vy, wz=wz, duration=duration)


def bool_to_launch(value: bool) -> str:
    return "true" if value else "false"


def bool_to_sick_flag(value: bool) -> str:
    return "1" if value else "0"


def resolve_use_ekf(run_mode: str, requested: bool | None) -> bool:
    if requested is not None:
        return requested
    return run_mode != "bench"


def resolve_cmd_topics(command: str, requested: str | None) -> str:
    if requested:
        return requested
    if command == "localization-stack":
        return DEFAULT_LOCALIZATION_CMD_TOPICS
    return DEFAULT_CMD_TOPICS


def resolve_with_base_link_crop(command: str, requested: bool | None) -> bool:
    if requested is not None:
        return requested
    return command == "mapping-stack"


def render_command(command: Sequence[str]) -> str:
    return " ".join(shlex.quote(part) for part in command)


def map_paths(maps_dir: str, map_name: str) -> Tuple[Path, Path, Path]:
    base = Path(maps_dir)
    pbstream = base / f"{map_name}.pbstream"
    filestem = base / map_name
    yaml_file = base / f"{map_name}.yaml"
    return pbstream, filestem, yaml_file


def run_foreground_command(
    command: Sequence[str],
    dry_run: bool = False,
) -> int:
    print(f"$ {render_command(command)}")
    if dry_run:
        return 0
    completed = subprocess.run(command, check=False)
    return int(completed.returncode)


def run_checked_command(
    command: Sequence[str],
    timeout_sec: float = 10.0,
) -> int:
    print(f"$ {render_command(command)}")
    try:
        completed = subprocess.run(
            command,
            check=False,
            timeout=timeout_sec,
        )
    except subprocess.TimeoutExpired:
        print(f"[TIMEOUT] command exceeded {timeout_sec:.1f}s")
        return 124
    return int(completed.returncode)


def read_key(timeout_sec: float) -> str:
    ready, _, _ = select.select([sys.stdin], [], [], timeout_sec)
    if not ready:
        return ""
    key = sys.stdin.read(1)
    if key == "\x1b":
        while select.select([sys.stdin], [], [], 0)[0]:
            sys.stdin.read(1)
        return ""
    return key


@dataclass(frozen=True)
class MotionSegment:
    vx: float
    vy: float
    wz: float
    duration: float


PRESET_MOTIONS: Dict[str, List[MotionSegment]] = {
    "forward_stop": [
        MotionSegment(0.45, 0.0, 0.0, 2.5),
        MotionSegment(0.0, 0.0, 0.0, 0.5),
    ],
    "strafe_test": [
        MotionSegment(0.0, 0.35, 0.0, 1.5),
        MotionSegment(0.0, -0.35, 0.0, 1.5),
        MotionSegment(0.0, 0.0, 0.0, 0.5),
    ],
    "spin_scan": [
        MotionSegment(0.0, 0.0, 0.7, 2.0),
        MotionSegment(0.0, 0.0, -0.7, 2.0),
        MotionSegment(0.0, 0.0, 0.0, 0.5),
    ],
    "box_loop": [
        MotionSegment(0.35, 0.0, 0.0, 2.0),
        MotionSegment(0.0, 0.0, 0.7, 1.6),
        MotionSegment(0.35, 0.0, 0.0, 2.0),
        MotionSegment(0.0, 0.0, 0.7, 1.6),
        MotionSegment(0.35, 0.0, 0.0, 2.0),
        MotionSegment(0.0, 0.0, 0.7, 1.6),
        MotionSegment(0.35, 0.0, 0.0, 2.0),
        MotionSegment(0.0, 0.0, 0.7, 1.6),
        MotionSegment(0.0, 0.0, 0.0, 0.5),
    ],
}


MOTION_PAD_BINDINGS = {
    "1": "forward_stop",
    "2": "strafe_test",
    "3": "spin_scan",
    "4": "box_loop",
}
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

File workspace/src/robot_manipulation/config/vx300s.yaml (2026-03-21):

port: /dev/ttyDXL

joint_order: [waist, shoulder, elbow, forearm_roll, wrist_angle, wrist_rotate, gripper]
sleep_positions: [0, -1.85, 1.55, 0, 0.8, 0, 0]

joint_state_publisher:
  update_rate: 20
  publish_states: true
  topic_name: joint_states

groups:
  arm: [waist, shoulder, elbow, forearm_roll, wrist_angle, wrist_rotate]

grippers:
  gripper:
    horn_radius: 0.022
    arm_length: 0.036
    left_finger: left_finger
    right_finger: right_finger

shadows:
  shoulder:
    shadow_list: [shoulder_shadow]
    calibrate: true
  elbow:
    shadow_list: [elbow_shadow]
    calibrate: true

sisters:

motors:
  waist:
    ID: 1
    Baud_Rate: 3
    Return_Delay_Time: 0
    Drive_Mode: 0
    Velocity_Limit: 131
    Min_Position_Limit: 0
    Max_Position_Limit: 4095
    Secondary_ID: 255

  shoulder:
    ID: 2
    Baud_Rate: 3
    Return_Delay_Time: 0
    Drive_Mode: 1
    Velocity_Limit: 131
    Min_Position_Limit: 841
    Max_Position_Limit: 2867
    Secondary_ID: 255

  shoulder_shadow:
    ID: 3
    Baud_Rate: 3
    Return_Delay_Time: 0
    Drive_Mode: 0
    Velocity_Limit: 131
    Min_Position_Limit: 841
    Max_Position_Limit: 2867
    Secondary_ID: 2

  elbow:
    ID: 4
    Baud_Rate: 3
    Return_Delay_Time: 0
    Drive_Mode: 1
    Velocity_Limit: 131
    Min_Position_Limit: 898
    Max_Position_Limit: 3094
    Secondary_ID: 255

  elbow_shadow:
    ID: 5
    Baud_Rate: 3
    Return_Delay_Time: 0
    Drive_Mode: 0
    Velocity_Limit: 131
    Min_Position_Limit: 898
    Max_Position_Limit: 3094
    Secondary_ID: 4

  forearm_roll:
    ID: 6
    Baud_Rate: 3
    Return_Delay_Time: 0
    Drive_Mode: 1
    Velocity_Limit: 131
    Min_Position_Limit: 0
    Max_Position_Limit: 4095
    Secondary_ID: 255

  wrist_angle:
    ID: 7
    Baud_Rate: 3
    Return_Delay_Time: 0
    Drive_Mode: 1
    Velocity_Limit: 131
    Min_Position_Limit: 830
    Max_Position_Limit: 3504
    Secondary_ID: 255

  wrist_rotate:
    ID: 8
    Baud_Rate: 3
    Return_Delay_Time: 0
    Drive_Mode: 0
    Velocity_Limit: 131
    Min_Position_Limit: 0
    Max_Position_Limit: 4095
    Secondary_ID: 255

  gripper:
    ID: 9
    Baud_Rate: 3
    Return_Delay_Time: 0
    Drive_Mode: 0
    Velocity_Limit: 131
    Min_Position_Limit: 0
    Max_Position_Limit: 4095
    Secondary_ID: 255

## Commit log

2025-10-27 Add sample files + Template for node service action
2025-11-11 Add Collision Avoidance with ESP32 and Ultrasonic Sensor
    [ultrasonic.ino]
2025-11-12 Ultrasonic works with USB but Services fails
2025-11-13 Launch script for Basic SLAM(cartographer))
    Upload basic launch file, fix the remapping of the frame_id in rviz, create own lua file pico_2d.lua for the cartographer to read those parameters. Still have multiple TFs, will need to fix the synchonization problem
2025-11-14 Update distance_sensor.py for UART tx rx pins testing
2025-11-14 UART pins (TX/RX) with ESP32 works
2025-11-15 Code for 1 motor and complete IK testing
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2025-11-17 Upload code for uart/i2c/default
2025-11-18 write the python script to parse the keyboard input into the velocity for the chasis
2025-11-18 Adding I2C communication for 5 servo motors
2025-11-18 Camera, Product Mock, Ultrasonic, Central, Works tgt
2025-11-18 add demo code for servo
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2025-11-20 Remove the redundant code for uart and seperate default mode to local file
    Tested with the I2C and successful version of the I2C parsing of the velocity information from Jetson
2025-11-26 Update Teleop with wheel motors
2025-12-01 Gazebo for robotics arm
    [five_dof_arm.urdf]
2025-12-01 Gazebo bridge ROS2 ?? not working
    [arm_controllers.yaml, five_dof_arm.urdf]
2025-12-08 Update Doc
    [five_dof_arm.urdf]
2025-12-15 Complete migration to new package
    [arm_controllers.yaml, five_dof_arm.urdf]
2025-12-15 Modify minor errors from merging
    [servo_arm_i2c.c]
2025-12-15 Add explanation about ROS2 Camera Node + Recheck Basic Robotics Arm
    Robotics Arm need to be rechecked once having CAD or final design
    - Set the limit of each joint
    - Right now only having predefined motion of each state needs to find a way to use Intel RealSense as feedback loop
    - Stop motion for safety
2025-12-31 Restructured Workspace
    For better development (Follow Industry and Professional Standard)
    Separate Packages for each part and each team member
    [arm_controllers.yaml, five_dof_arm.urdf]
2026-01-02 STM32 working code for base controller
2026-01-10 8 Ultrasonic Sensors Extension + I2C
2026-01-12 firebase basic function sample
2026-01-15 Main Script + Tree for each case
2026-01-18 Upload the complete untested Base control Code
    CAN bus communication and basic control code is done testing
2026-01-18 Change the code to reflect the on board usart pins for control
    By sending the hex format of the motion data, the motor can successfully rotated at the same time, further testing is required since the motor is still pretty shaky, so extra logic is needed and bett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
2026-01-18 Update new pid parameters
2026-01-19 Fix the PID first try
2026-01-20 Update a new version of robot control code
    [daplink.cfg, stlink.cfg, 云台重力补偿.xlsx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]
2026-01-20 Update working code for base control
    Everything working pretty well！
2026-01-20 Fix the rotation direction of left side of motors
2026-02-03 Upload the NAV2 compatible node (RX/TX))
    This node will receive the information from the NAV2 through the /cmd_vel to send speed in the frame format that STM32 understand. It will also receive the base odom from the uart to give the TF for 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
2026-02-06 Reduce data transmission to solve for frame mismatch
    Reduce the data so the default baudrate can handle the odom info data
2026-02-06 Uploaded fix version
    Reduced the odom data sending frequency. Also change the parameters of the nav2 and the picoscan to match the need of the naming of the frame id. Rewrite the file to indicate the changed workflow.
    [nav2_serial_bridge.py]
2026-02-06 update the frame mismatch fix
    [nav2_serial_bridge.py]
2026-02-06 Fix of TF try 3rd
    [nav2_serial_bridge.py]
2026-02-09 Update a 2nd fix decoupling uart with serialplot
    [nav2_serial_bridge.py]
2026-02-09 stm32: move serialplot path from UART3 to shared UART2
2026-02-09 change the firmware to support fragmented frames
2026-02-09 revert one change back to old version
    [nav2_serial_bridge.py]
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2026-02-12 Version 2 (Fixing some parts based on feedback)
    Task Left
    - Zoom in/ Zoom out
    - Category for grocery
    - Multiple Languages
    - Image in database
    - Delete item button in employee mode
    - Filling in qty for customer
    - Track order ID in database
2026-02-18 Packaging the navigation，mapping and teleoperation into ROS2 package
    First attempt of packaging already working workflow into ROS2 package，waiting to be tested. The way of use is inside the Repo readme.
2026-02-24 Modify package description in setup.py
    Updated the package description to focus on Navigation and Wheel Controller.
2026-02-25 Update Code for Linear Actuator
2026-02-26 Collision Detection Integrated with uart-serial module
    [nav2_serial_bridge.py]
2026-02-27 Updated the geometry of the base and add detail test plan to the next stage
2026-02-27 Create camera node
    This node does only two things:
    It uses D435i IMU data to publish camera feedback TF (parent_frame -> camera_feedback_frame) for arm motion correction in MoveIt.
    It detects products with YOLO + depth, then publishes object TF (camera_feedback_frame -> object_i) for grasp targeting.
    It also publishes:
    detections_json (detection results),
    detection_point (3D points),
    optional debug image (camera/color/image_raw).
2026-02-27 Add arm description + bringup packages (ROS2 workspace inside repo)
2026-02-27 Migrate robot_manipulation to C++ and add PickArm action for moveit
    [arm_controller.yaml, arm_motor.yaml]
2026-03-03 Update Values: Might need to abandon Moveit2
    [arm_controllers.yaml, arm_motor.yaml]
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2026-03-03 Add Predefined Action Server for Robotics Arm
2026-03-05 Add gazebo for robotic arms + urdf from Feng
    [20kg_Servo_1.stl, RDS_Servo_1.stl, RDS_Servo_2.stl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]
2026-03-05 Revert "partially working autonomous job"
    This reverts commit 43a5ba1c5d60a817e3b28bf900ca31b3646e4e00.
    [nav_assistant.py]
2026-03-05 Revert "3rd version of the autonomous mapping and navigation, waiting verification"
    This reverts commit 9a6e55aaf346a415b0ee16359dca3838e319274f.
    [nav_assistant.py]
2026-03-05 Revert "Update Naviagtion for auto saving map"
    This reverts commit b4a72096f2586784cdfc6e8bd9364c337d856d48.
    [nav2_serial_bridge.py, nav_assistant.py]
2026-03-05 Revert "2nd autonomous version waiting for testing"
    This reverts commit 122887e6106cd03ab2b8e66fa2de33867a2bf352.
    [nav_assistant.py]
2026-03-05 Revert "First autonomous movement wating for verification"
    This reverts commit bb582881e2a94a565b509c64a34fc363efc2915b.
    [nav_assistant.py, teleop_cmd_vel.py, teleop_cmd_vel_collision.py]
2026-03-09 Fleet Manager Prototype
    SLAM Map, Ask AI, Store Map left
2026-03-11 Update dimesion for accurate lidar positioning and enable IMU usage in cartographer
2026-03-15 Add vx300 manipulation MoveIt support
    [ar_tag.stl, ar_tag.urdf.xacro, base.stl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]
2026-03-15 Vendor Interbotix sources into main repository
    [RealSenseD415.sdf, TrossenRoboticsOfficeBuilding.sdf, VisionKit.sdf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]
2026-03-15 Improve the map of the current GUI and hook it with Realtime SLAM
2026-03-19 Change Default arm to 6DOF version and fix TF mismatch with doc updated
    Refactor camera TF semantics for auto-pick and switch manipulation defaults to VX300S
    What actually changed:
    Replaced the legacy camera_feedback frame with an explicit camera TF chain:
    ee_gripper_link -> camera_mount_frame -> camera_color_optical_frame
    Published detection points and object TFs in the optical frame
    Updated vision_auto_pick to consume the new camera_optical_frame / point_camera_optical_m payload
    Switched default robot model / base-frame related defaults from vx300 to vx300s
    Updated launch files, config, scripts, and docs to match the new TF semantics and 6DOF setup
    [vx300_auto_pick.yaml]
2026-03-20 adding the image of the hand-eye calibration & change the launch files
2026-03-20 Prepare for the eye-inhand calibration and update readme, need to reverse forearm motor rotation
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2026-03-26 updated readme and new target for calibration and cleanly seperate measure/calibrated tf
2026-03-26 fix rotation problem and calibration works
    [viperx_arm_server.yaml, vx300_auto_pick.yaml, vx300s_auto_pick.yaml]
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2026-03-28 Prep for Custom Arm + Racking after SICK challenge
2026-03-30 Improve ViperX BT auto-pick and camera grasp logic
2026-04-02 Store Map update change to adapt to lab environment
    Change the semantic map and update rotation function to slots and products
2026-04-26 Add readme for CAD files of mechanical components
2026-04-26 all robotic arm files
    [20kg_Servo.SLDPRT, RDS_Servo.SLDPRT, assembly_robotic_arm.SLDASM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]
2026-04-27 Reorganize Files + Upload QR Code + User Manual
    [Aluminium.SLDPRT, Base.SLDPRT, Bearing 688ZZ.SLDPRT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]
